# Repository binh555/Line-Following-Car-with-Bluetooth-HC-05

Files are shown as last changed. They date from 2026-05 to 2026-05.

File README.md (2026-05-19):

# 🚗 STM32 Line Follower Robot

An automatic line-following car using the STM32 Nucleo F401RE, wireless control via HC-05 Bluetooth, wheel speed measurement with Hall encoders, and line tracking with 5 infrared sensors. The control algorithm uses a PD (Proportional-Derivative) controller.

<!-- car photo -->
xe2
xe1

---

## Table of Contents

- [Features](#features)
- [Hardware](#hardware)
- [Wiring Diagram](#wiring-diagram)
- [Software Configuration](#software-configuration)
- [Control Algorithm](#control-algorithm)
- [Bluetooth Commands](#bluetooth-commands)
- [Technical Notes](#technical-notes)

---

## Features

- **AUTO mode** — the car follows the line automatically and adjusts the speed of both wheels using a PD controller
- **MANUAL mode** — manual control via Bluetooth (W/S/A/D), supports key auto-repeat from terminal software
- **STOP mode** — complete stop, disables the driver STBY pin
- **Auto stop on all-black** — detects the finish line after 40 consecutive stable cycles
- **Encoder report every 1 second** — prints LeftPPS / RightPPS and the status of 5 sensors through both UART2 (USB debug) and HC-05 (Bluetooth)
- **UART ring buffer without DMA** — Bluetooth RX/TX is fully interrupt-driven and non-blocking
- **Mechanical bias compensation** — `LEFT_PWM_BIAS` / `RIGHT_PWM_BIAS` compensate for real speed differences between the two wheels

---

## Hardware

| Component | Model / Specification |
|---|---|
| Microcontroller | STM32 Nucleo F401RE (STM32F401RET6, 84 MHz) |
| Motor | DC Servo GA12 N20, 12 V, gear ratio 1:150 |
| Wheels | 43 mm rubber wheels |
| Encoder | Hall sensor integrated in GA12 N20, 7 pulses/channel/motor revolution |
| Motor driver | TB6612FNG (VM ≤ 15 V, Iout ≤ 1.2 A continuous) |
| Line sensor | 5 infrared sensors (active LOW on black line) |
| Bluetooth | HC-05 (baud rate 9600, Slave mode) |
| Power supply | 12 V DC battery |

**Detailed encoder specifications:**
- 7 pulses / channel / motor shaft revolution (before gearbox)
- Gear ratio 1:150 → 1,050 pulses / wheel revolution (per channel)
- The current code uses 1 channel with rising edge detection → PPS = revolutions/second × 1,050
- Encoder supply: 3.3 V or 5 V — **never use 12 V**

---

## Wiring Diagram

### TB6612FNG ↔ STM32

| TB6612 | STM32 Pin | Description |
|---|---|---|
| STBY | PA6 | Driver enable (HIGH = ON) |
| AIN1 | PB1 | Motor A direction (left wheel) |
| AIN2 | PA8 | Motor A direction (left wheel) |
| PWMA | PB10 (TIM2_CH3) | Motor A PWM |
| BIN1 | PC7 | Motor B direction (right wheel) |
| BIN2 | PB6 | Motor B direction (right wheel) |
| PWMB | PA7 (TIM3_CH2) | Motor B PWM |
| VM | 12 V | Motor power |
| VCC | 3.3 V | Logic power |
| GND | GND | Common ground |

### Infrared sensors (5 sensors)

| Sensor | STM32 Pin | Physical position |
|---|---|---|
| S0 (far left) | PA0 | Leftmost |
| S1 | PA1 | |
| S2 (center) | PA4 | Center |
| S3 | PB0 | |
| S4 (far right) | PC1 | Rightmost |

> Logic: `0` = no line, `1` = black line detected (active LOW, sensor pulls down to GND on black)

### Encoder

| Signal | STM32 Pin | Interrupt |
|---|---|---|
| Left encoder (channel A) | PA15 | EXTI15 (rising edge) |
| Right encoder (channel A) | PB5 | EXTI9_5 (rising edge) |

### HC-05 Bluetooth

| HC-05 | STM32 Pin | UART |
|---|---|---|
| TXD | PA10 (USART1_RX) | USART1 |
| RXD | PA9 (USART1_TX) | USART1 |
| VCC | 5 V | |
| GND | GND | |

### UART2 Debug (USB → MobaXterm)

| Signal | STM32 Pin |
|---|---|
| TX | PA2 (USART2_TX) |
| RX | PA3 (USART2_RX) |

---

## Software Configuration

### Clock

```txt
HSI 16 MHz → PLL → SYSCLK = 84 MHz
APB1 = 42 MHz  (TIM2, TIM3 timer clock = 84 MHz due to timer x2 multiplier)
APB2 = 84 MHz  (USART1)
```

### PWM

| Parameter | Value |
|---|---|
| Timer | TIM2 (left wheel, CH3 - PB10) \| TIM3 (right wheel, CH2 - PA7) |
| Prescaler | 3 → timer input clock = 84 MHz / 4 = 21 MHz |
| Period | 1499 |
| PWM frequency | 21 MHz / 1500 ≈ 14 kHz |
| PWM_MAX (tick) | 1499 → 100% duty = 12 V |
| PWM_MIN_RUN | 250 → duty ~16.7% (minimum threshold for motor startup) |

### UART

| UART | Used for | Baud rate | Mode |
|---|---|---|---|
| USART1 | HC-05 Bluetooth | 9600 | Interrupt TX + Interrupt RX |
| USART2 | USB debug | 115200 | Blocking TX |

---

## Control Algorithm

### Line position calculation (weighted average)

The 5 sensors are assigned position weights of 0, 1000, 2000, 3000, and 4000:

```txt
position = Σ(i × 1000 × sensor[i]) / Σ(sensor[i])
```

The center position is 2000. If no sensor is active, the system switches to line-search mode (`searchLine`).

### Noise filtering

```txt
filteredPosition = 0.45 × filteredPosition + 0.55 × rawPosition
```

### PD controller

```c
error      = (filteredPosition - 2000) / 1000        // normalized unit: -2..+2
dError     = error - lastError
correction = KP × error + KD × dError
correction = clamp(correction, -MAX_CORRECTION, +MAX_CORRECTION)

leftSpeed  = BASE_SPEED + correction
rightSpeed = BASE_SPEED - correction
```

Both wheels are clamped within `[MIN_AUTO_SPEED, MAX_SPEED]`.

### Sharp turn handling

If `filteredPosition ≤ 500` or `≥ 3500` (line is near the outer edge):

- `filteredPosition ≤ 500` → left = 30%, right = MAX_SPEED *(sharp left turn)*
- `filteredPosition ≥ 3500` → left = MAX_SPEED, right = 30% *(sharp right turn)*

### Line search when lost

- `lastSeenSide < 0` → turn left (left = -SEARCH_REVERSE, right = +SEARCH_FORWARD)
- `lastSeenSide > 0` → turn right (left = +SEARCH_FORWARD, right = -SEARCH_REVERSE)
- unknown → move slowly forward (30%)

### Stop on all-black (finish line)

If all 5 sensors continuously detect the line for **40 control cycles** (40 × 3 ms = 120 ms):
1. Switch to `CAR_MODE_STOP`
2. Disable STBY
3. Print a message through both UART2 and Bluetooth

---

## Bluetooth Commands

Connect to HC-05 using MobaXterm or any serial terminal (baud rate 9600).

### Mode commands

| Command | Function |
|---|---|
| `U` | Switch to AUTO mode — line following |
| `M` | Switch to MANUAL mode — manual control |
| `X` | STOP — stop the car and disable the driver |
| `H` | Print HELP — list of commands |
| `T` | Print STATUS — current mode, position, PWM, sensors |

### MANUAL commands *(only active in MANUAL mode)*

| Command | Function | Auto-stop timeout |
|---|---|---|
| `W` | Forward | 250 ms after the last character |
| `S` | Backward | 500 ms after the last character |
| `A` | Turn left | 120 ms after the last character |
| `D` | Turn right | 120 ms after the last character |

> **Timeout note:** Terminal software does not send a signal when the key is released. A quick press = the car moves in one short pulse and then stops automatically. Holding the key = the terminal auto-repeats the character, so the car keeps moving until the key is released.

Commands are case-insensitive (`w` = `W`).

---

## Technical Notes

### Mechanical speed limit (1:150 motor)

The GA12 N20 motor with a 1:150 gear ratio at 12 V no-load typically reaches about 100–150 RPM after the gearbox. With 43 mm wheels:

```txt
Theoretical maximum speed ≈ π × 0.043 m × 150 RPM / 60 ≈ 0.34 m/s
```

This is the physical upper limit. If higher speed is needed, use a motor with a smaller gear ratio such as 1:50 or 1:30.

### Bluetooth ring buffer

Both Bluetooth TX and RX use interrupt-driven ring buffers:
- RX: `BT_RX_BUF_SIZE = 64` bytes — enough for 1-character commands
- TX: `BT_TX_BUF_SIZE = 256` bytes — enough for one full report line
- Non-blocking — the `main()` loop never stalls waiting for UART

### Interrupt priority

| Interrupt | Priority | Reason |
|---|---|---|
| USART1 (HC-05) | 0 (highest) | Prevent Bluetooth byte loss |
| EXTI15_10 (left encoder) | 1 | Accurate pulse counting |
| EXTI9_5 (right encoder) | 1 | Accurate pulse counting |

### Notes when using MobaXterm / serial terminal

The terminal does not send a separate byte when a key is released, so MANUAL mode uses timeout-based auto-stop. If the car feels jerky during manual control, adjust these constants:

```c
#define MANUAL_FWD_RELEASE_TIMEOUT_MS   250U
#define MANUAL_BWD_RELEASE_TIMEOUT_MS   500U
#define MANUAL_TURN_RELEASE_TIMEOUT_MS  120U
```

Increase the timeout → the car moves longer after each key press.  
Decrease the timeout → the car stops faster after key release.

---

## License

MIT License — free to use, modify, and distribute.

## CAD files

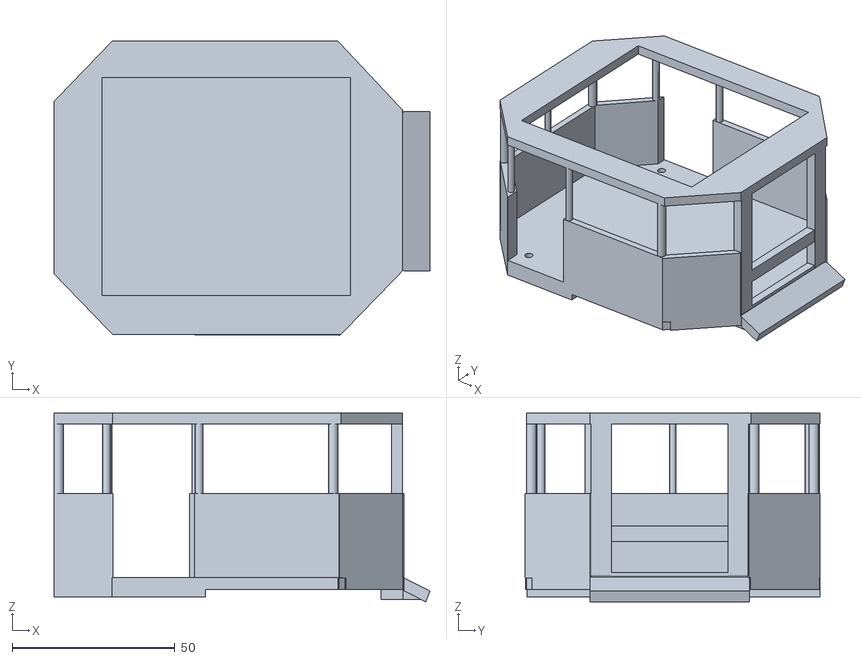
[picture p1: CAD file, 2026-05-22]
Mini-Car-3D-Design.stl
115.6 x 90.6 x 58.0

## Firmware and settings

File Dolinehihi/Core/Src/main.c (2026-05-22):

#include "main.h"
#include "motor.h"
#include "sensor.h"
#include "pid.h"
#include "encoder.h"
#include "bluetooth.h"

TIM_HandleTypeDef htim2;
TIM_HandleTypeDef htim3;
UART_HandleTypeDef huart1;
UART_HandleTypeDef huart2;

void SystemClock_Config(void){}
void MX_GPIO_Init(void){}
void MX_TIM2_Init(void){}
void MX_TIM3_Init(void){}
void MX_USART1_UART_Init(void){}
void MX_USART2_UART_Init(void){}

int main(void){
    HAL_Init();
    SystemClock_Config();
    MX_GPIO_Init();
    MX_TIM2_Init();
    MX_TIM3_Init();
    MX_USART1_UART_Init();
    MX_USART2_UART_Init();

    HAL_TIM_PWM_Start(&htim2,TIM_CHANNEL_3);
    HAL_TIM_PWM_Start(&htim3,TIM_CHANNEL_2);
    tb6612_standby(0);
    stopMotor();
    HAL_Delay(START_DELAY_MS);

    bluetoothStartRx();

    while(1){
        bluetoothTask();
        lineControlTask();
        reportEncoderAndSensors();
    }
}

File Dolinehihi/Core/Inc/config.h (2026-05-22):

#ifndef CONFIG_H
#define CONFIG_H

/* SENSOR */
#define SENSOR_COUNT 5
#define SENSOR_ACTIVE_BLACK 0

/* MOTOR */
#define PWM_MAX 999
#define PWM_MIN_RUN 180
#define LEFT_PWM_BIAS 20
#define RIGHT_PWM_BIAS 22
#define LEFT_MOTOR_INVERT 0
#define RIGHT_MOTOR_INVERT 1

#define BASE_SPEED 95.0f
#define MAX_SPEED 100.0f
#define SEARCH_FORWARD_SPEED 90.0f
#define SEARCH_REVERSE_SPEED 20.0f

/* CONTROL */
#define CONTROL_INTERVAL_MS 3U
#define DEBUG_INTERVAL_MS 500U
#define REPORT_INTERVAL_MS 1000U
#define START_DELAY_MS 1000U
#define LINE_CENTER_POS 2000.0f
#define KP 34.0f
#define KD 32.0f
#define MAX_CORRECTION 60.0f
#define MIN_AUTO_SPEED 36.0f

#define STOP_ON_ALL_BLACK 1
#define ALL_BLACK_CONFIRM_CYCLES 40U

/* MANUAL */
#define MANUAL_FWD_RELEASE_TIMEOUT_MS 250U
#define MANUAL_BWD_RELEASE_TIMEOUT_MS 500U
#define MANUAL_TURN_RELEASE_TIMEOUT_MS 120U

#endif

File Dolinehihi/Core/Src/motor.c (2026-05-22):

#include "stm32f4xx_hal.h"
#include "main.h"
#include "config.h"
#include "pinmap.h"
#include "motor.h"

static int16_t lastLeftPwm = 0;
static int16_t lastRightPwm = 0;

static float clamp_f32(float x, float mn, float mx){
    if(x<mn) return mn;
    if(x>mx) return mx;
    return x;
}

static int16_t clamp_i16(int32_t x,int16_t mn,int16_t mx){
    if(x<mn) return mn;
    if(x>mx) return mx;
    return (int16_t)x;
}

static int16_t percentToSignedPwm(float percent,int16_t bias){
    float mag; int32_t pwm;
    percent = clamp_f32(percent,-100.0f,100.0f);
    if(percent>-0.5f && percent<0.5f) return 0;
    mag = (percent>=0.0f)?percent:-percent;
    pwm = (int32_t)(mag*PWM_MAX/100.0f);
    if(pwm>0){ pwm+=bias; if(pwm<PWM_MIN_RUN) pwm=PWM_MIN_RUN; if(pwm>PWM_MAX) pwm=PWM_MAX;}
    return (percent>=0.0f)?(int16_t)pwm:(int16_t)(-pwm);
}

static void setLeftMotorPwmSigned(int16_t pwm){
#if LEFT_MOTOR_INVERT
    pwm=-pwm;
#endif
    pwm=clamp_i16(pwm,-PWM_MAX,PWM_MAX);
    if(pwm>=0){
        HAL_GPIO_WritePin(AIN1_PORT,AIN1_PIN,GPIO_PIN_SET);
        HAL_GPIO_WritePin(AIN2_PORT,AIN2_PIN,GPIO_PIN_RESET);
        __HAL_TIM_SET_COMPARE(PWMA_TIM,PWMA_CHANNEL,pwm);
    }else{
        HAL_GPIO_WritePin(AIN1_PORT,AIN1_PIN,GPIO_PIN_RESET);
        HAL_GPIO_WritePin(AIN2_PORT,AIN2_PIN,GPIO_PIN_SET);
        __HAL_TIM_SET_COMPARE(PWMA_TIM,PWMA_CHANNEL,-pwm);
    }
    lastLeftPwm=pwm;
}

static void setRightMotorPwmSigned(int16_t pwm){
#if RIGHT_MOTOR_INVERT
    pwm=-pwm;
#endif
    pwm=clamp_i16(pwm,-PWM_MAX,PWM_MAX);
    if(pwm>=0){
        HAL_GPIO_WritePin(BIN1_PORT,BIN1_PIN,GPIO_PIN_SET);
        HAL_GPIO_WritePin(BIN2_PORT,BIN2_PIN,GPIO_PIN_RESET);
        __HAL_TIM_SET_COMPARE(PWMB_TIM,PWMB_CHANNEL,pwm);
    }else{
        HAL_GPIO_WritePin(BIN1_PORT,BIN1_PIN,GPIO_PIN_RESET);
        HAL_GPIO_WritePin(BIN2_PORT,BIN2_PIN,GPIO_PIN_SET);
        __HAL_TIM_SET_COMPARE(PWMB_TIM,PWMB_CHANNEL,-pwm);
    }
    lastRightPwm=pwm;
}

void tb6612_standby(uint8_t enable){ HAL_GPIO_WritePin(STBY_PORT,STBY_PIN,enable?GPIO_PIN_SET:GPIO_PIN_RESET); }
void stopMotor(void){ setLeftMotorPwmSigned(0); setRightMotorPwmSigned(0); }
void setMotorPercent(float l,float r){ setLeftMotorPwmSigned(percentToSignedPwm(l,LEFT_PWM_BIAS)); setRightMotorPwmSigned(percentToSignedPwm(r,RIGHT_PWM_BIAS)); }
void manualForward(void){ setMotorPercent(100.0f,100.0f);}
void manualBackward(void){ setMotorPercent(-80.0f,-80.0f);}
void manualLeft(void){ setMotorPercent(-35.0f,100.0f);}
void manualRight(void){ setMotorPercent(100.0f,-35.0f);}

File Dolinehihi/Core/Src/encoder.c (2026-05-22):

#include "encoder.h"
#include "main.h"
#include <stdio.h>
#include <string.h>   // fix strlen warning

volatile uint32_t leftPulseCount=0;
volatile uint32_t rightPulseCount=0;
static uint32_t lastLeftCount=0;
static uint32_t lastRightCount=0;

void reportEncoderAndSensors(void){
    uint32_t leftPPS=leftPulseCount-lastLeftCount;
    uint32_t rightPPS=rightPulseCount-lastRightCount;
    lastLeftCount=leftPulseCount;
    lastRightCount=rightPulseCount;

    char msg[180];
    snprintf(msg,sizeof(msg),"[AUTO REPORT] LeftPPS=%lu RightPPS=%lu\r\n",leftPPS,rightPPS);
    HAL_UART_Transmit(&huart2,(uint8_t*)msg,strlen(msg),10);
}

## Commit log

2026-05-19 Create README.md for STM32 Line Follower Robot
    Add detailed README for STM32 Line Follower Robot project
2026-05-19 Revise motor driver and line sensor details
    Updated motor driver and line sensor descriptions for clarity.
